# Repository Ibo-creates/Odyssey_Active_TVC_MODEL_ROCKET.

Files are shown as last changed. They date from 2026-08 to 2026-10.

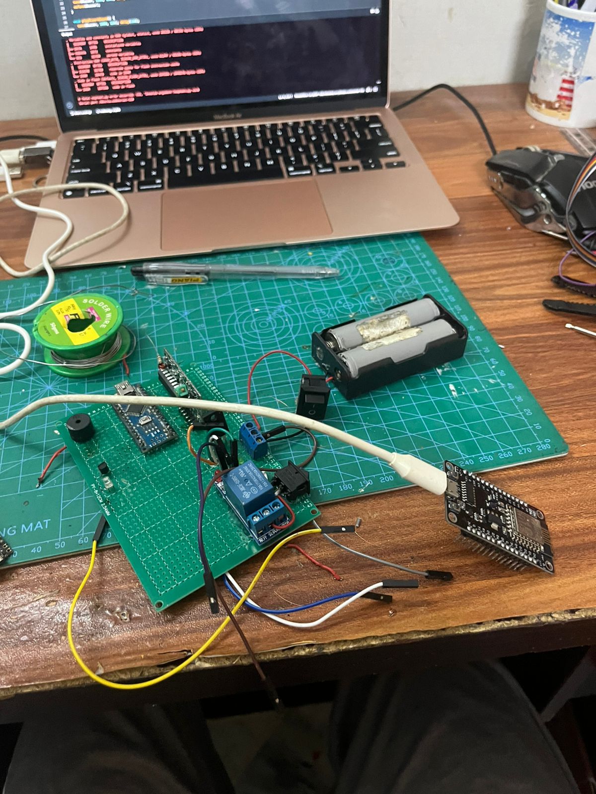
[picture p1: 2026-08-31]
media/LaunchPad ignition /images/Debugging setup.jpeg

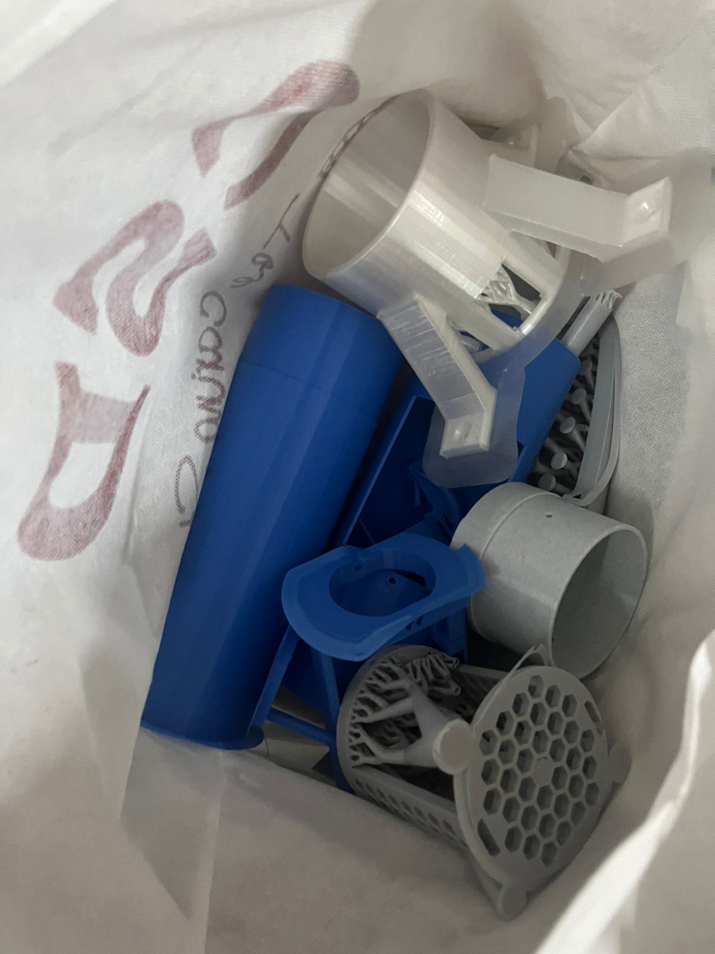
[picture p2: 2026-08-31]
media/rocket/images/Raw parts.jpeg

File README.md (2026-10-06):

# 🚀 Odyssey

rocekt

### A Thrust Vector Controlled Rocket

> **Odyssey** is an actively stabilized rocket featuring a custom 2-axis Thrust Vector Control (TVC) system with a parachute mechansim , a custom flight computer packed MPU6050 IMU, PID-based control, and onboard flight-data logging, which handles , G-forces, yaw, pitch and PID calulations.
> This also includes a custom launch radio remote Igniton system.

## Overview

### Demo: https://youtube.com/shorts/ixf_WoA4taA?si=kmYzy9-NjBv1ve3l

(A flight hasnt be logged yet due to restrictions of commerically available rocket motors in my country)

It has been a dream of mine to build a guided rocket, for which I explored an alternative method to conventional fins rocket stablization, and Thrust vector control instead. This works by moving the rocket's motor using a custom 2 axis servo gimble, yaw and pitch, relying on correction angles received from the flight computer running a custom PID algrothim. 

Odyssey also has a custom Launch-pad radio controlled Igniton system, which helps ignite the rocket's motor safely using custom e-matches. 

At apogee the rocket's mechnical nose opens with the help of a servo, revealing a parachute that brings the rocket back safely to the ground.

The flight log data is then recorded into a 8 gb SD card, which can be later read and visualised using excel 2d graphs feature. 

## Features

### Rocket

* Dry mass of approximately: 1kg
* height: 60 cm
* Outer diameter : 9.2 cm
* Rocket motor class to be used : Estes G class motor

* Vertical IMU Mounting: Custom math engine tailored for vertical IMU orientation.
* Flight State Machine: Automated transitions through PAD, IGNITION, COAST, APOGEE, and LANDED states.
* Barometric and IMU Telemetry: Live logging of altitude, acceleration, attitude angles, and PID servo outputs directly to an onboard microsd card.
* Fully custom 3d printed design.
* 2-axis TVC gimble.
* Automatic parachute mechanical syetem at apogee.
* Onboard data logging.

### Wireless Launch System

* Wireless launch command
* 3 step launch verfication.
* Remote ignition control
* Launch system status indicator

### Parameters logged

| Parameter | Description |
| --- | --- |
| Time_ms | Timestamp |
| State | Current flight state |
| Pitch | Estimated pitch angle |
| Yaw | Estimated yaw angle |
| Altitude | BMP280 altitude |
| GForce | Calculated total acceleration |
| OutputPitch | TVC pitch correction |
| OutputYaw | TVC yaw correction |

The controller continuously compares the desired Yaw and Pitch with the measured ones. The resulting error is processed by the PID controller, which generates a TVC command. The Output result then send a correction angle for the servos to move in a way that steers the rocket back to the vertical axis, the loop repeats until desired postion is reached.

## Flight state machine

PAD
 │
 │ Liftoff detected
 
IGNITION
 │
 │ Burnout detected
 
COAST
 │
 │ Apogee detected
 
APOGEE
 │
 │ Deployment
 
LANDED
## Control and Mathematics Overview

### PID Control math 

Odyssey uses a PD controller to convert attitude error into TVC servo corrections:

#### Controller Parameters

| Axis  |  Kp |  Ki | Kd |
| ----- | --: | --: | ---: |
| Pitch | 1.2 | 0 | 0.05 |
| Yaw | 2.0 | 0 | 0.10 |

## Hardware Electronics 

### Flight computer

|  # | Component | Quantity |
| -: | :--- | ---: |
|  1 | Arduino Uno | 1 |
|  2 | MPU6050 IMU | 1 |
|  3 | BMP280 Barometric Sensor | 1 |
|  4 | MicroSD Card Module | 1 |
|  5 | Servo Motors | 3 |
|  6 | Buzzer | 1 |
|  7 | NPN Transistor | 1 |
|  8 | 5mm Green LED | 1 |
|  9 | Toggle Switch | 1 |
| 10 | LM7805 5V Voltage Regulator | 2 |
| 11 | 18650 Li-ion Cells | 2 |
| 12 | 4 × 6 cm Perfboard | 1 |
| 13 | M4 × 6 mm Screws | 14 |

### LaunchPad igniton
|  # | Component | Quantity |
| -: | --- | ---: |
|  1 | Arduino MKR WiFi 1000 | 1 |
|  2 | 4-Channel NIC2262/2272 Wireless Remote + Receiver Module | 1 |
|  3 | 5V Relay | 1 |
|  4 | LM7805 5V Voltage Regulator | 1 |
|  5 | Buzzer | 1 |
|  6 | NPN Transistor | 1 |
|  7 | 5mm LED | 1 |
|  8 | Diode | 1 |
|  9 | ON/OFF Switch | 1 |
| 10 | 18650 Li-ion Cells | 3 |
| 11 | 8 × 12 cm Perfboard. | 1 |

## Pinout and Wiring

### Flight computer

| Arduino Uno Pin | Component | Function |
| --- | --- | --- |
| **A4 / SDA** | MPU6050 | I²C Data |
| **A5 / SCL** | MPU6050 | I²C Clock |
| **A4 / SDA** | BMP280 | I²C Data |
| **A5 / SCL** | BMP280 | I²C Clock |
| **D10** | SD Card | Chip Select |
| **D11** | SD Card | MOSI |
| **D12** | SD Card | MISO |
| **D13** | SD Card | SCK |
| **D5** | TVC Servo X | Pitch control |
| **D6** | TVC Servo Y | Yaw control |
| **D9** | Chute Servo | Parachute deployment |
| **D3** | Buzzer | Audio status |
| **D2** | Green LED | Status indicator |

### Ignition launch pad

| Arduino Pin | Connected To | Function |
| --- | --- | --- |
| **D3** | Radio Receiver CH1 | Sequence input 1 |
| **D4** | Radio Receiver CH2 | Sequence input 2 |
| **D5** | Radio Receiver CH3 | Sequence input 3 |
| **D6** | Relay control | Launch output |
| **D7** | Green LED | Status |
| **D1** | Buzzer | Audio feedback |

## Onshape Public link: 

https://cad.onshape.com/documents/43eb36db9af5306ca3d18e96/w/deaf376eb42987b9b3412347/e/4c195a71d6f593436827596b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

## Software Setup

Required Arduino Libraries
Install the following libraries using the Arduino Library Manager:

1.Adafruit BMP280 Library
2.Servo library 
3.Wire & SPI (Built-in)

### How to upload the code

1. Copy the code from firware repositry
2. select your com port where the arduino is attached
3. Select the right board e.g " Arduino uno"
4. Click upload

## Sd card data logging

### Heres how to read the data from sd card

1. Take out the sd card from the flight computer.
2. Insert it into a laptop or pc using an sd card reader usb.
3. Export the LOG.csv files into excel, google sheets or numbers ( for mac).
4. Make a Seperate column left to the Time_ms, and write to the 2nd row of the new column " = B2/1000 " , drag the yellow box to the end of the column.
5. Filter the time period you want to visualise.
6. Select the two columns you would like to plot on a 2d graph, e.g Altitude at Y axis and Time in seconds in X axis.
7. Click on the " insert " option, select the " Scatter graph with smooth lines " .

---

**Odyssey — Ground Tested · Flight Pending**

Built for **Hack Club Macondo 2026**.

## License

Software in this repository is released under the **MIT License**.

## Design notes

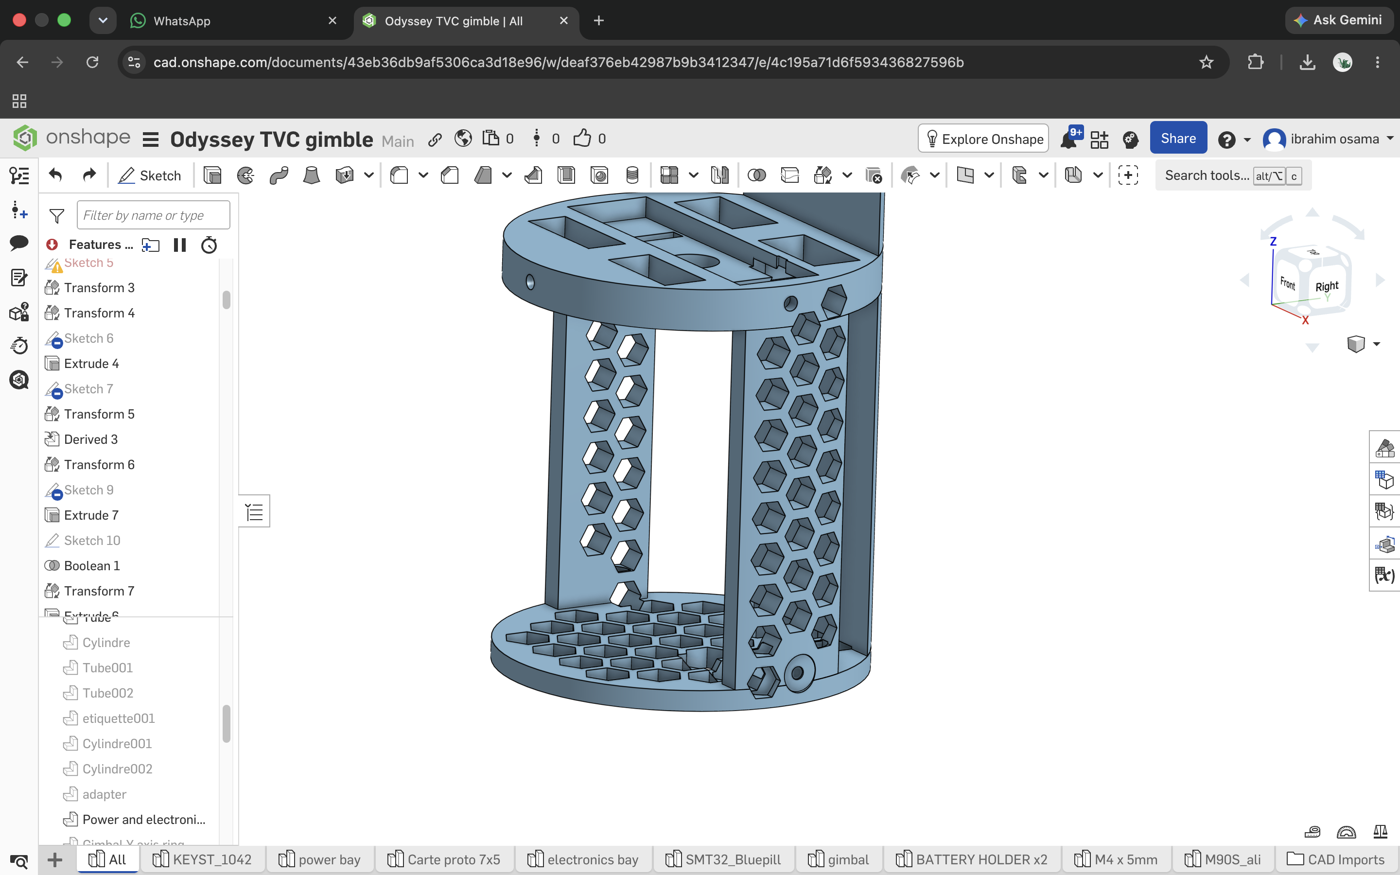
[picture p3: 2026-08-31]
media/rocket/images/Electronics bay.png

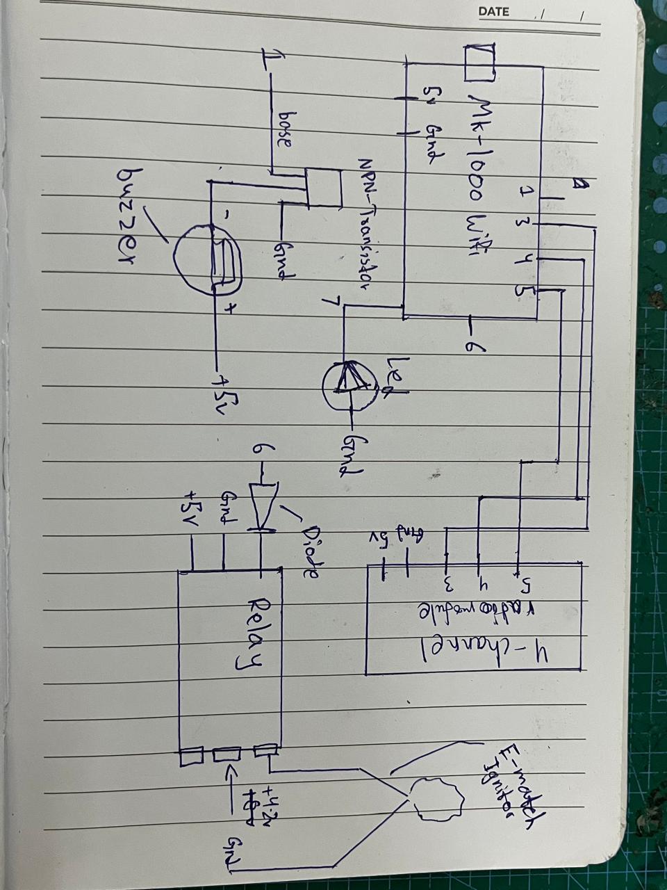
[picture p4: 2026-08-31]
Wiring diagram /Launch pad Ignition/Electronics.jpeg

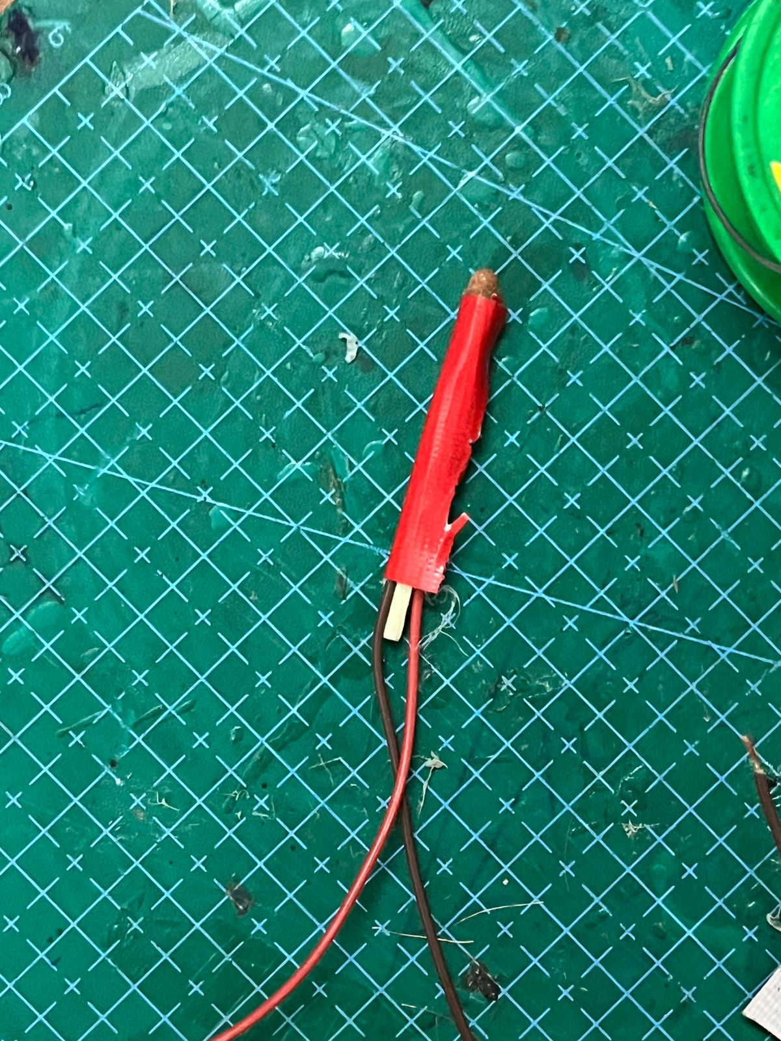
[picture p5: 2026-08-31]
media/LaunchPad ignition /images/E match.jpeg

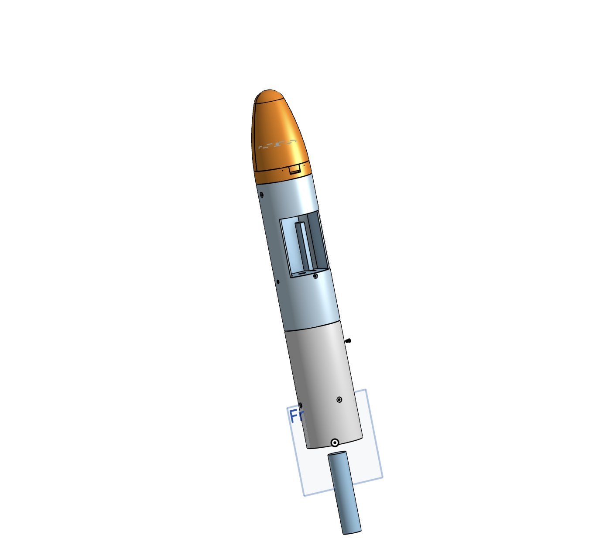
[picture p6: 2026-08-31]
media/rocket/images/Cad rocket.png

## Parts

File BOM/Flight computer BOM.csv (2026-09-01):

# | Component | Specification | Qty | Cost | Supplier | Link
1 | Arduino Uno | ATmega328P | 1 | $ 27.6 | Amazon | https://www.amazon.com/Arduino-A000066-ARDUINO-UNO-R3/dp/B008GRTSV6?utm_source=chatgpt.com
2 | MPU6050 | 6-Axis IMU | 1 | $ 8.99 | Amazon | https://www.amazon.com/dp/B09TVYVC6X
3 | BMP280 | Barometric Sensor | 1 | $5.49 | Amazon | https://www.amazon.com/dp/B01ICN5QPU
4 | MicroSD Module | SPI | 1 | $6.99 | Amazon | https://www.amazon.com/dp/B07BJ2P6X6
5 | MicroSD Card | 8 GB | 1 | $11.84 | Amazon | https://www.amazon.com/dp/9983039281
7 | Mg 90 Servo Motor | Parachute Deployment/ gamble | 3 | $8.68 x 3 = $26.04 | Amazon | https://www.amazon.com/dp/B0BHYHKF2P
8 | Active Buzzer | 5 V | 1 | $7.99 | Amazon | https://www.amazon.com/QMseller-Terminals-Raspberry-Electronic-Continous/dp/B07VRK7ZPF
9 | NPN Transistor | Switching / Driver | 1 | $8.99 | Amazon | https://www.amazon.ca/-/fr/2N3904-Power-transistors-jonction-bipolaire/dp/B0DMVQSLWF?th=1
10 | Green LED | 5 mm | 1 | $7.99 | Amazon | https://www.amazon.com/dp/B01AUI4VVA?th=1
11 | Toggle Switch | Power | 1 | $6.99 | Amazon | https://www.amazon.com/-/es/EGSCST/dp/B0FH26ZN3N?th=1
12 | LM7805 | 5 V Regulator | 2 | $4.99 | Amazon | https://www.amazon.com/Regulator-Integrated-Circuits-Positive-Regulators/dp/B0BRV3YRK3?th=1
13 | 18650 Cell | Li-ion | 2 | $5.38 | Aliexpress | https://www.aliexpress.com/item/1005007910903881.html?utm_source=chatgpt.com
14 | Perfboard | 5 x 7 cm | 1 | $6.99 | Amazon | https://www.amazon.com/dp/B012YZ2Q4G?ref=clp_cat_p_2
15 | M4 pan head screws | 6mm | 14 | $6.99 | Amazon | https://www.amazon.com/dp/B07YS7RXN9
Total Cost | - | - | - | $143.26 | - | -

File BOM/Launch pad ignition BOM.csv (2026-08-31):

# | Component | Specification | Qty | Cost | Supplier | Link
1 | Arduino MKR WiFi 1000 | Microcontroller | 1 | $59.80 | Aliexpress | https://www.aliexpress.com/item/1005012576306573.html
2 | Wireless Rf remote module | IC2272 4-Channel Wireless RF Transceiver Module | 1 | $12.99 | Amazon | https://www.amazon.ca/Channel-Wireless-Control-Transmitter-Receiver/dp/B00XDTG644
3 | Relay | 5 V | 1 | $1.86 | Aliexpress | https://www.aliexpress.com/item/1005012716803241.html
4 | LM7805 | 5 V Regulator | 1 | $4.99 | Amazon | https://www.amazon.com/Regulator-Integrated-Circuits-Positive-Regulators/dp/B0BRV3YRK3?th=1
5 | Buzzer | 5 V | 1 | $7.99 | Amazon | https://www.amazon.com/QMseller-Terminals-Raspberry-Electronic-Continous/dp/B07VRK7ZPF
6 | NPN Transistor | Switching / Driver | 1 | $8.99 | Amazon | https://www.amazon.ca/-/fr/2N3904-Power-transistors-jonction-bipolaire/dp/B0DMVQSLWF?th=1
7 | Green LED | 5 mm | 1 | $7.99 | Amazon | https://www.amazon.com/dp/B01AUI4VVA?th=1
8 | Diode | Relay protection | 1 | $6.99 | Amazon | https://www.amazon.com/dp/B083DXTTXS
9 | ON/OFF Switch | Main Power | 1 | $5.99 | Amazon | https://www.amazon.com/clp/B01N2U8PK0
10 | 18650 Cell | Li-ion | 3 | $8.07 | Amazon | https://www.aliexpress.com/item/1005007910903881.html?utm_source=chatgpt.com
11 | Perfboard | 8 × 12 cm | 1 | $5.54 | Aliexpress | https://www.aliexpress.com/item/1890414289.html
Total Cost | - | - | - | $131.2 | - | -

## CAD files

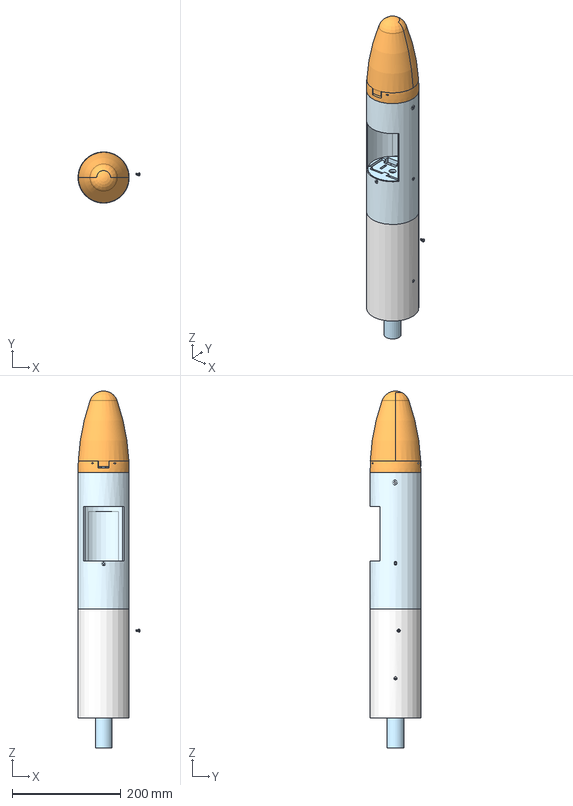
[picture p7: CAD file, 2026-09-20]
Assembly 1 (1).step
113.8 x 94.0 x 655.2 mm
Gimabl X axis ring
etiquette001 x 3
axe x 3
Cylindre002 x 3
Tube x 3
Power and electronics bay
Nose seat
etiquette x 3
Gimbal Y axis ring
Tube002 x 3
M4 x 5mm v2
Lower tube
Cylindre x 3
base001 x 3
Cylindre001 x 3
Upper tube
Tube001 x 3
Nose flap 1
Nose base
adapter
Nose flap 2
Motor tube
motortube

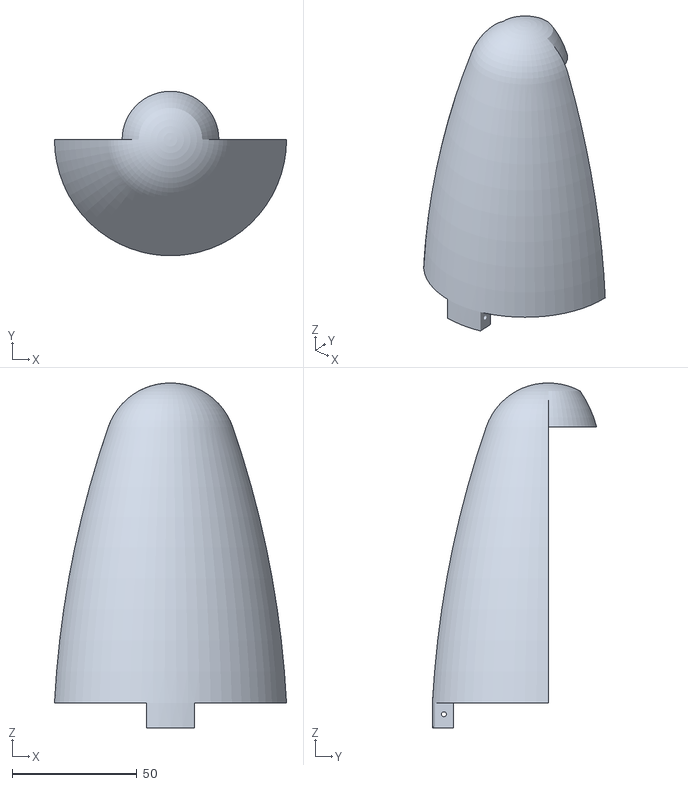
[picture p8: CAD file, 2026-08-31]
3d models /3d printing models/All - Nose flap 2.stl
92.9 x 65.8 x 138.1

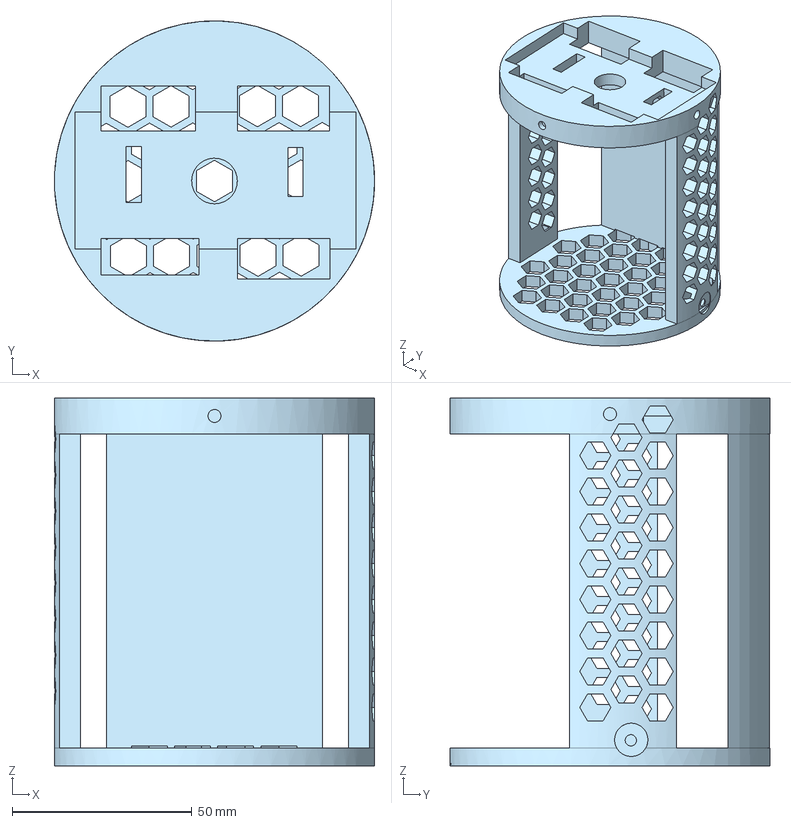
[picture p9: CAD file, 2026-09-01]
3d models /Step models/All - Power and electronics bay (1).step
89.0 x 89.0 x 102.3 mm

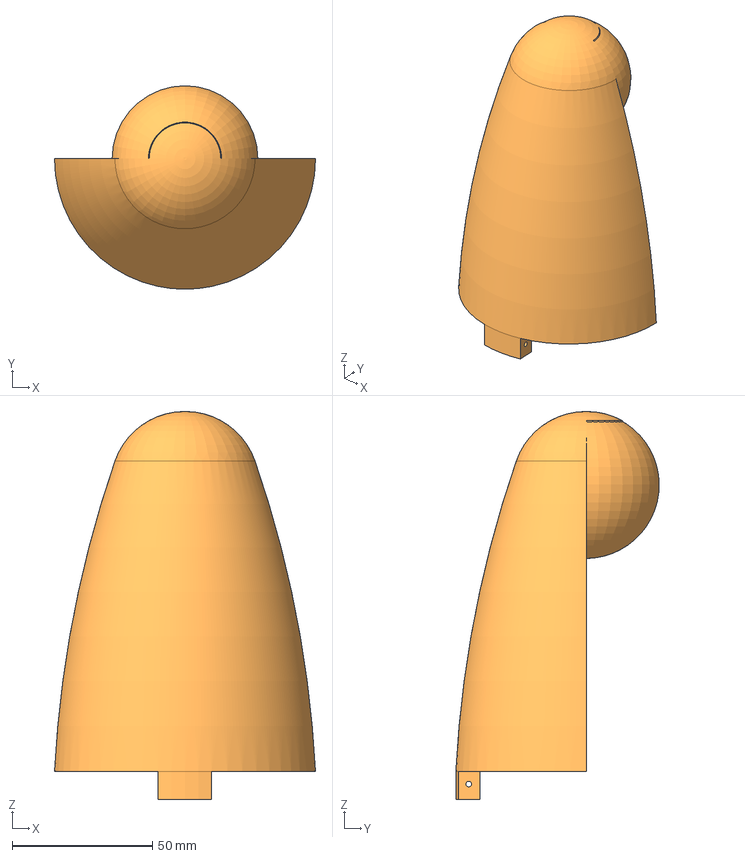
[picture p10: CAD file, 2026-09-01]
3d models /Step models/All - Nose flap 2 (1).step
92.9 x 72.4 x 138.1 mm

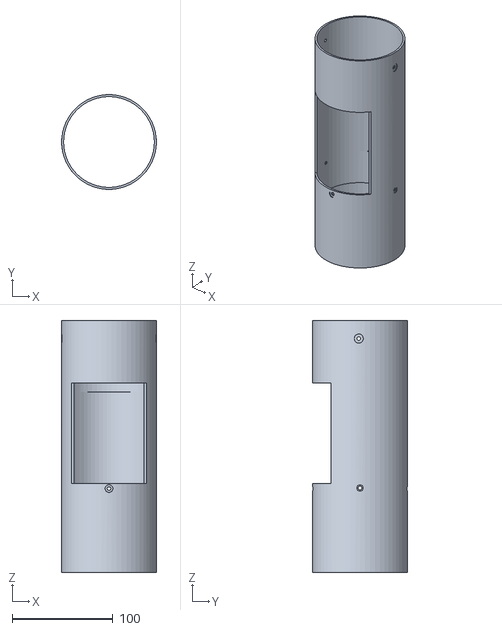
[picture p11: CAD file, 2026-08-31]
3d models /3d printing models/All - Upper tube.stl
94.0 x 94.0 x 250.0

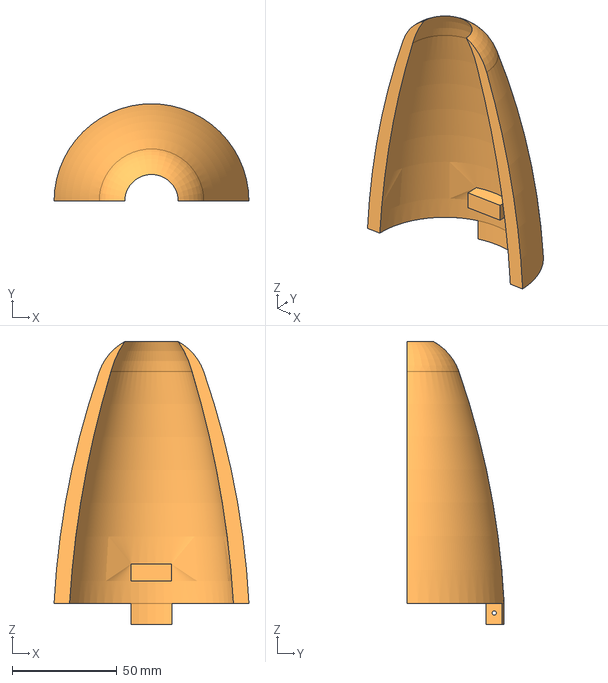
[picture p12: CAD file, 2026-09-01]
3d models /Step models/All - Nose flap 1 (1).step
92.9 x 46.5 x 134.9 mm

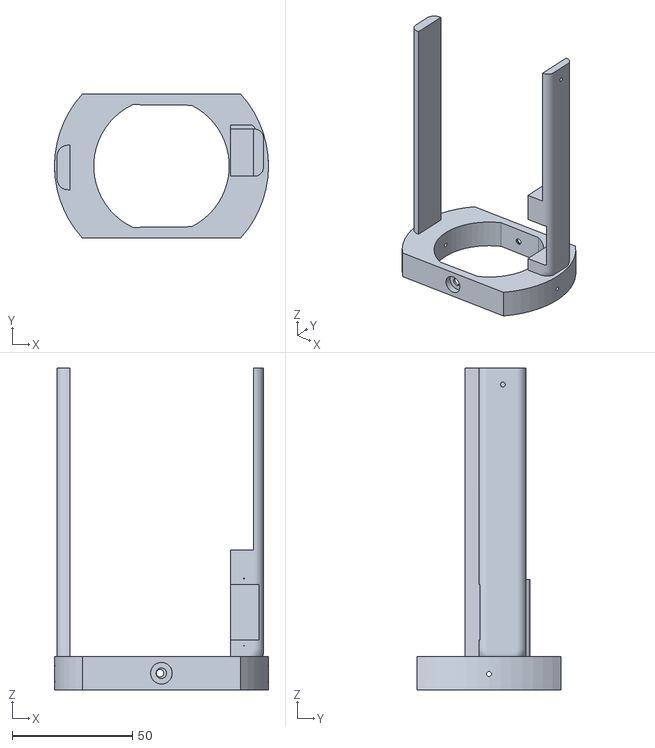
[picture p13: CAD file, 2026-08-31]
3d models /3d printing models/All - Gimabl X axis ring (3).stl
89.0 x 60.0 x 133.9

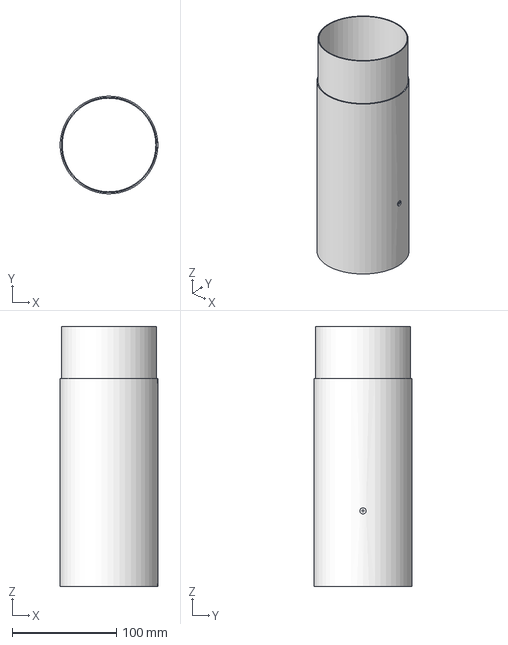
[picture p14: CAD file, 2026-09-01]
3d models /Step models/All - Lower tube (1).step
94.0 x 94.0 x 250.0 mm

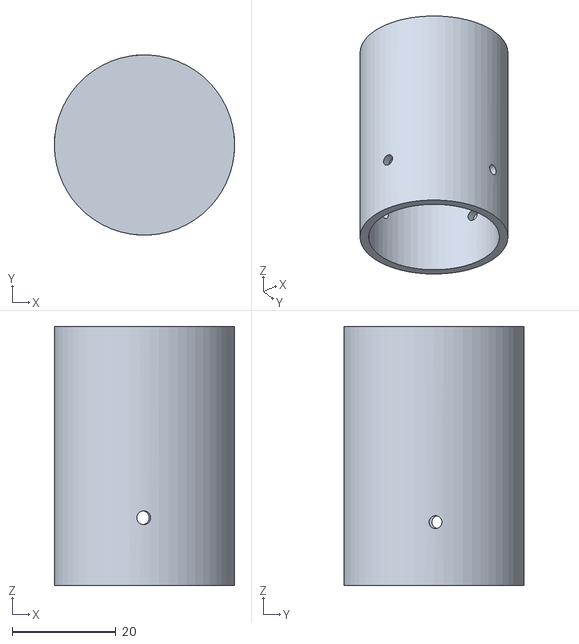
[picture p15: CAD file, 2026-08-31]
3d models /3d printing models/All - Motor tube.stl
34.8 x 34.8 x 50.0

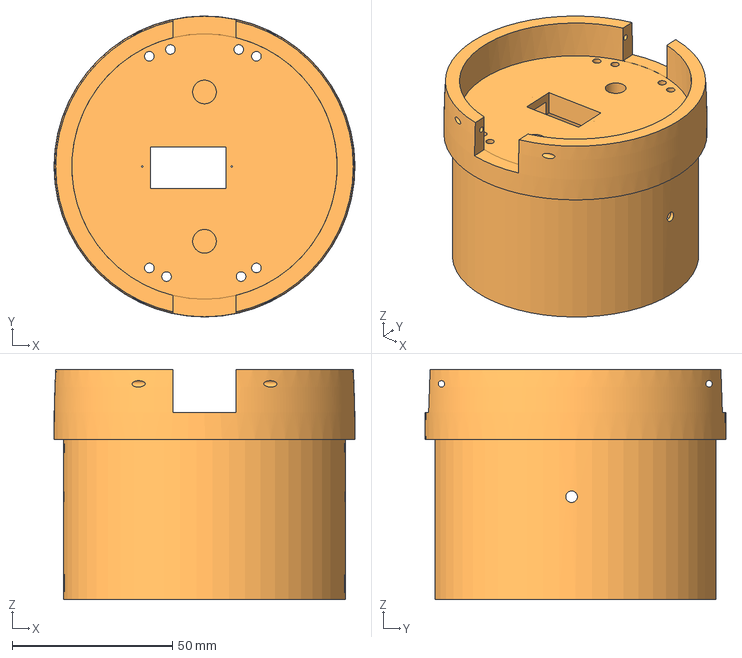
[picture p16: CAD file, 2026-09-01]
3d models /Step models/All - Nose base (1).step
94.0 x 94.0 x 71.9 mm

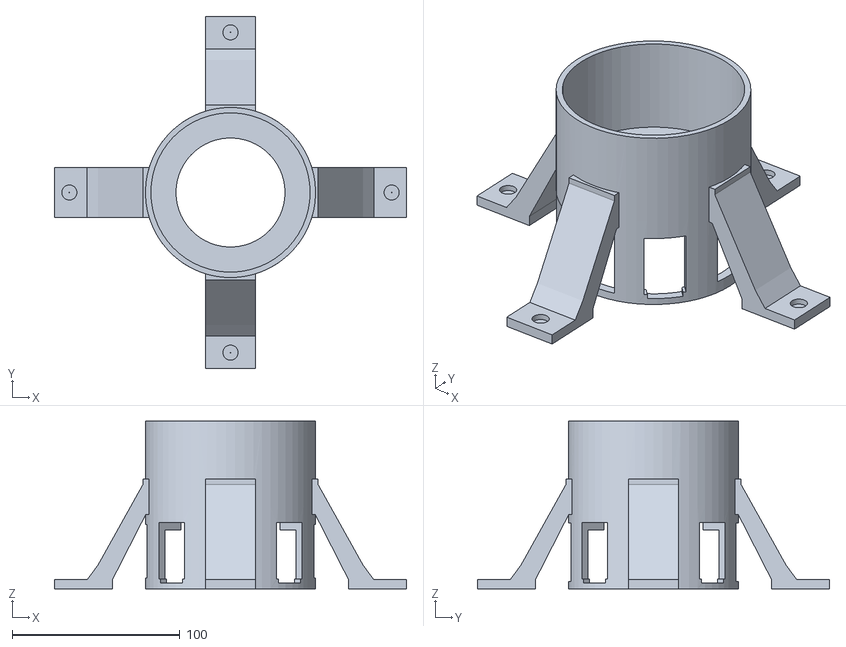
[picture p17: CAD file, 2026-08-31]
3d models /3d printing models/Launchpad.stl
210.0 x 210.0 x 100.0

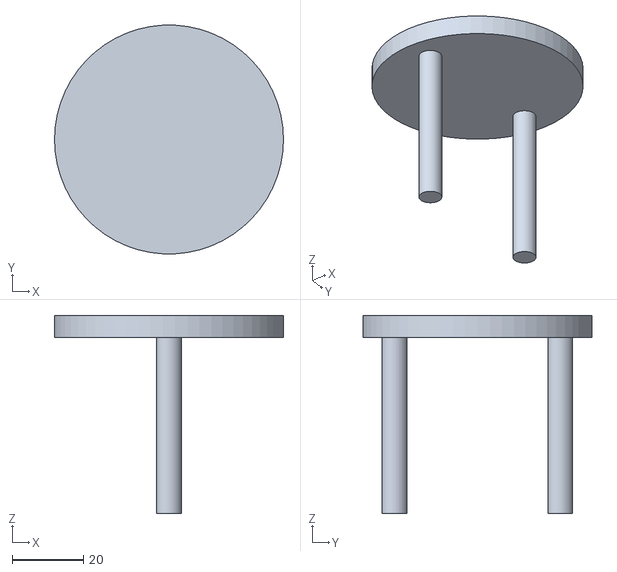
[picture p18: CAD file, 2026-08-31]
3d models /3d printing models/All - Nose seat (1).stl
64.4 x 64.3 x 55.8

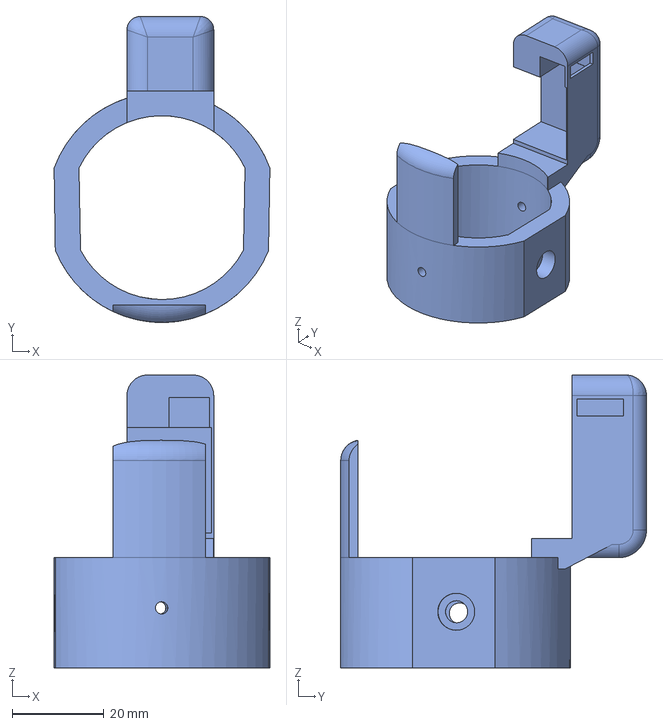
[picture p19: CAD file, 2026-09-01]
3d models /Step models/All - Gimbal Y axis ring (1).step
46.9 x 66.6 x 63.7 mm

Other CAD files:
3d models /3d printing models/All - Power and electronics bay (4).stl
3d models /Step models/All - Upper tube (1).step
3d models /3d printing models/All - Nose flap 1.stl
3d models /Step models/All - Motor tube (1).step
3d models /3d printing models/All - Nose base (5).stl
3d models /3d printing models/All - Gimbal Y axis ring (1).stl
3d models /3d printing models/All - Lower tube (1).stl
3d models /Step models/All - Gimabl X axis ring (1).step
3d models /Step models/All - Nose seat.step
3d models /Step models/Part Studio 1 - luanchpad.step

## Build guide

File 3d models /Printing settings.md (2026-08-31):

### 3D Printing Specifications

**Printer Nozzle:** 0.4 mm

Supports: On 
Filament: PETG

| Part | Material | Infill |
| --- | --- | -----: |
| Adapter | White | 15% |
| Gimbal X | Blue | 25% |
| Gimbal Y | White | 25% |
| Lower Tube | Blue | 100% |
| Motor Tube | Blue | 100% |
| Nose Base | White | 15% |
| Nose Flap 1 | White | 15% |
| Nose Flap 2 | White | 15% |
| Nose Seat | Blue | 25% |
| Power & Electronics Bay | White | 15% |
| Upper Tube | Blue | 100% |

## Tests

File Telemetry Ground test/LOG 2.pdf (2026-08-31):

## Altitude

## State

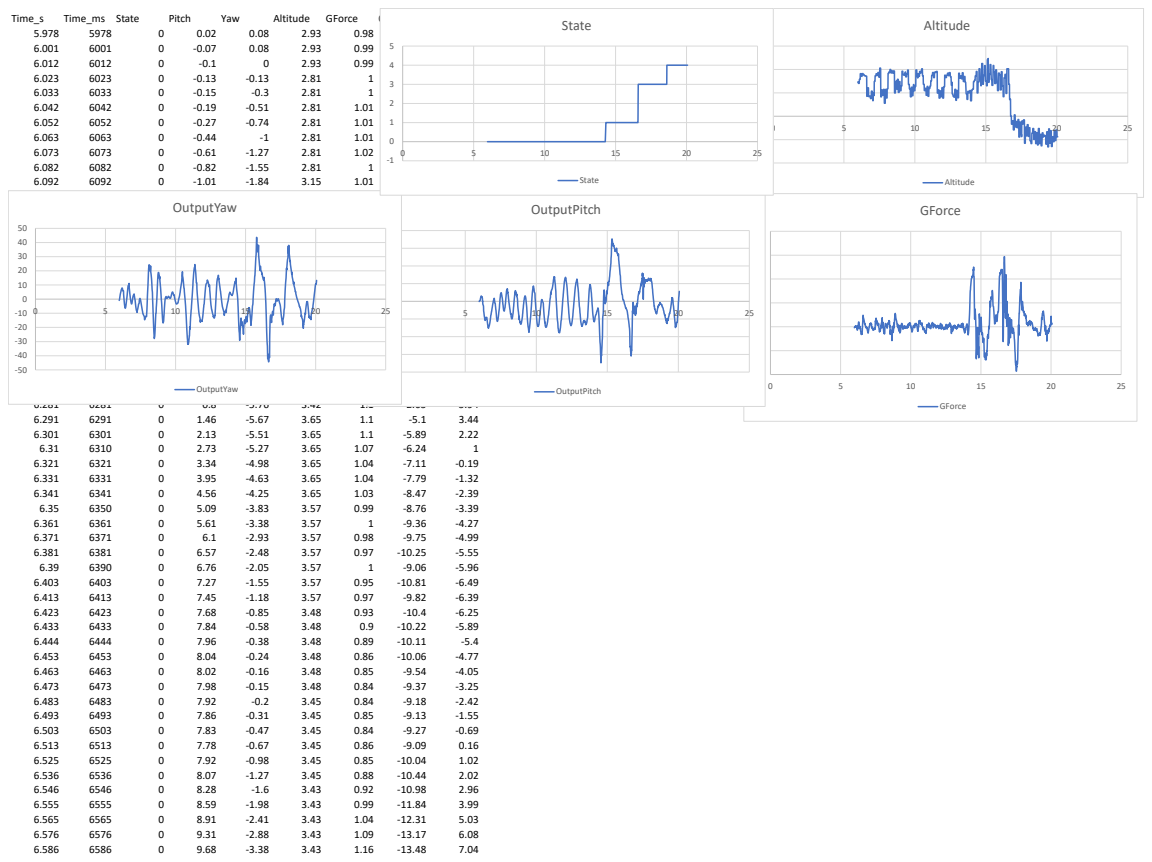
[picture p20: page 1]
Time_s; Time_ms State; Pitch; Yaw; Altitude; GForce; OutputPitchOutputYaw; OutputPitch; OutputYaw; State

6.147 6147 | 0 | -1.89 | -3.5 3.15 | 30 0.99
6.157 6157 | 0 | -1.95 | -3.84 3.64 | 20 0.97

2.7 7.08
2.66 7.41

6.197 6197 | 0 | -1.97 | -5.08 3.64 | 0.93 -20
6.207 6207 | 0 | -1.83 | -5.32 3.64 | 0.95 -30

1.99 7.74
1.54 7.47

6.595 | 6595
0 | 10.15 | -3.91 | 3.43 | 1.24 | -14.55 | 7.95
6.605 | 6605
0 | 10.59 | -4.45 | 3.43 | 1.24 | -14.88 | 8.69
6.616 | 6616
0 | 10.93 | -4.98 | 1.7 | 1.21 | -14.81 | 9.22
6.626 | 6626
0 | 11.24 | -5.5 | 1.7 | 1.18 | -15.03 | 9.52
6.635 | 6635
0 | 11.51 | -5.97 | 1.7 | 1.18 | -15.15 | 9.56
6.645 | 6645
0 | 11.69 | -6.38 | 1.7 | 1.17 | -14.94 | 9.31
6.683 | 6683
0 | 11.53 | -7.48 | 2.43 | 1.12 | -13.63 | 11.1
6.692 | 6692
0 | 11.51 | -7.67 | 2.43 | 1.1 | -13.68 | 8.29
6.703 | 6703
0 | 11.43 | -7.77 | 2.43 | 1.08 | -13.32 | 7.17
6.713 | 6713
0 | 11.3 | -7.79 | 2.43 | 1.06 | -12.9 | 6.08
6.723 | 6723
0 | 11.13 | -7.74 | 2.43 | 1.07 | -12.51 | 5.06
6.732 | 6732
0 | 10.93 | -7.63 | 2.43 | 1.05 | -12.12 | 4.1
6.743 | 6743
0 | 10.68 | -7.49 | 1.68 | 1.04 | -11.59 | 3.22
6.753 | 6753
0 | 10.38 | -7.31 | 1.68 | 1.04 | -10.9 | 2.38
6.763 | 6763
0 | 10.05 | -7.1 | 1.68 | 1.03 | -10.45 | 1.58
6.772 | 6772
0 | 9.66 | -6.86 | 1.68 | 1.02 | -9.61 | 0.8
6.782 | 6782
0 | 9.26 | -6.6 | 1.68 | 1.02 | -9.16 | 0.06
6.793 | 6793
0 | 8.79 | -6.32 | 1.68 | 0.99 | -8.17 | -0.65
6.805 | 6805
0 | 8.24 | -5.96 | 1.68 | 1 | -7.7 | -1.26
6.815 | 6815
0 | 7.87 | -5.67 | 1.71 | 0.98 | -7.62 | -1.92
6.825 | 6825
0 | 7.45 | -5.37 | 1.71 | 0.99 | -6.81 | -2.46
6.836 | 6836
0 | 7.05 | -5.06 | 1.71 | 1 | -6.48 | -2.91
6.845 | 6845
0 | 6.63 | -4.77 | 1.71 | 0.97 | -5.82 | -3.24
6.855 | 6855
0 | 6.27 | -4.5 | 1.71 | 0.97 | -5.73 | -3.41
6.865 | 6865
0 | 5.88 | -4.26 | 1.71 | 0.99 | -5.13 | -3.4
6.876 | 6876
0 | 5.48 | -4.06 | 1.51 | 0.98 | -4.54 | -3.21
6.885 | 6885
0 | 5.08 | -3.91 | 1.51 | 0.98 | -4.1 | -2.83
6.895 | 6895
0 | 4.67 | -3.82 | 1.51 | 0.95 | -3.59 | -2.3
6.905 | 6905
0 | 4.29 | -3.79 | 1.51 | 0.93 | -3.2 | -1.67
6.916 | 6916
0 | 3.85 | -3.82 | 1.51 | 0.93 | -2.46 | -1
6.925 | 6925
0 | 3.44 | -3.9 | 1.51 | 0.91 | -2.05 | -0.29
6.94 | 6940
0 | 2.86 | -4.09 | 2.15 | 0.88 | -1.42 | 0.41
6.949 | 6949
0 | 2.47 | -4.25 | 2.15 | 0.89 | -1.03 | 1.15
6.96 | 6960
0 | 2.11 | -4.44 | 2.15 | 0.87 | -0.74 | 1.71
6.97 | 6970
0 | 1.71 | -4.65 | 2.15 | 0.87 | -0.03 | 2.15
6.98 | 6980
0 | 1.34 | -4.86 | 2.15 | 0.9 | 0.24 | 2.47
6.989 | 6989
0 | 1 | -5.06 | 2.15 | 0.91 | 0.48 | 2.66
7.038 | 7038
0 | -0.3 | -5.81 | 1.33 | 1 | 1.71 | 3.66
7.05 | 7050
0 | -0.38 | -5.93 | 1.33 | 1 | 0.82 | 2.87
7.06 | 7060
0 | -0.37 | -5.99 | 1.33 | 1.02 | 0.38 | 2.29
7.069 | 7069
0 | -0.29 | -5.99 | 1.96 | 1.03 | -0.07 | 1.7
7.079 | 7079
0 | -0.12 | -5.95 | 1.96 | 1.06 | -0.69 | 1.04
7.09 | 7090
0 | 0.1 | -5.85 | 1.96 | 1.05 | -1.21 | 0.31
7.112 | 7112
0 | 0.45 | -5.48 | 1.96 | 1.06 | -1.3 | -0.76
7.122 | 7122
0 | 0.78 | -5.26 | 1.96 | 1.07 | -2.59 | -1.82
7.133 | 7133
0 | 1.11 | -4.99 | 1.77 | 1.07 | -3 | -2.75
7.142 | 7142
0 | 1.54 | -4.67 | 2.98 | 1.08 | -3.97 | -3.66
7.152 | 7152
0 | 2 | -4.31 | 2.98 | 1.08 | -4.74 | -4.53
7.162 | 7162
0 | 2.44 | -3.92 | 2.98 | 1.08 | -5.11 | -5.39
7.173 | 7173
0 | 2.97 | -3.5 | 2.98 | 1.04 | -6.23 | -6.15
7.183 | 7183
0 | 3.53 | -3.07 | 2.98 | 1.04 | -6.99 | -6.81
7.192 | 7192
0 | 4.11 | -2.63 | 2.98 | 1.04 | -7.88 | -7.41
7.202 | 7202
0 | 4.8 | -2.18 | 3.46 | 1.06 | -9.19 | -7.87
7.213 | 7213
0 | 5.41 | -1.75 | 3.46 | 0.98 | -9.53 | -8.15
7.223 | 7223
0 | 6 | -1.35 | 3.46 | 1 | -10.17 | -8.31
7.232 | 7232
0 | 6.57 | -0.97 | 3.46 | 0.98 | -10.71 | -8.34
7.25 | 7250
0 | 7.44 | -0.36 | 3.46 | 0.98 | -11.36 | -9.39

7.261 | 7261
0 | 7.82 | -0.07 | 3.46 | 0.97 | -11.31 | -8.33
7.27 | 7270
0 | 8.12 | 0.19 | 3.63 | 0.96 | -11.24 | -8.03
7.28 | 7280
0 | 8.33 | 0.42 | 3.63 | 0.95 | -11.03 | -7.7
7.29 | 7290
0 | 8.44 | 0.6 | 3.63 | 0.95 | -10.67 | -7.32
7.301 | 7301
0 | 8.48 | 0.75 | 3.63 | 0.93 | -10.38 | -6.89
7.31 | 7310
0 | 8.41 | 0.86 | 3.63 | 0.93 | -9.76 | -6.42
7.32 | 7320
0 | 8.26 | 0.94 | 3.63 | 0.96 | -9.14 | -5.91
7.33 | 7330
0 | 8.05 | 0.98 | 3.48 | 0.97 | -8.61 | -5.35
7.341 | 7341
0 | 7.75 | 0.99 | 3.48 | 0.94 | -7.8 | -4.74
7.351 | 7351
0 | 7.4 | 0.96 | 3.48 | 0.94 | -7.15 | -4.09
7.36 | 7360
0 | 6.98 | 0.89 | 3.48 | 0.96 | -6.28 | -3.43
7.398 | 7398
0 | 5.27 | 0.47 | 3.74 | 0.94 | -4.04 | -3.05
7.408 | 7408
0 | 4.71 | 0.32 | 3.74 | 0.95 | -2.86 | -1.43
7.417 | 7417
0 | 4.05 | 0.14 | 3.74 | 0.97 | -1.55 | -0.78
7.428 | 7428
0 | 3.41 | -0.05 | 3.74 | 0.95 | -0.91 | -0.25
7.438 | 7438
0 | 2.67 | -0.24 | 3.74 | 0.97 | 0.52 | 0.14
7.448 | 7448
0 | 1.91 | -0.42 | 3.74 | 0.96 | 1.52 | 0.4
7.458 | 7458
0 | 1.2 | -0.58 | 3.74 | 0.95 | 2.06 | 0.48
7.468 | 7468
0 | 0.52 | -0.71 | 3.34 | 1.05 | 2.81 | 0.38
7.478 | 7478
0 | -0.19 | -0.8 | 3.34 | 1.12 | 3.75 | 0.14
7.488 | 7488
0 | -0.82 | -0.84 | 3.34 | 1.11 | 4.14 | -0.19
7.498 | 7498
0 | -1.36 | -0.84 | 3.34 | 1.13 | 4.34 | -0.57
7.507 | 7507
0 | -1.83 | -0.8 | 3.34 | 1.14 | 4.57 | -1.04
7.518 | 7518
0 | -2.24 | -0.71 | 3.34 | 1.16 | 4.71 | -1.58
7.53 | 7530
0 | -2.59 | -0.55 | 4.12 | 1.18 | 4.55 | -2.28
7.54 | 7540
0 | -2.84 | -0.38 | 4.12 | 1.16 | 4.67 | -2.85
7.55 | 7550
0 | -2.98 | -0.17 | 4.12 | 1.13 | 4.23 | -3.47
7.56 | 7560
0 | -3 | 0.08 | 4.12 | 1.14 | 3.74 | -4.07
7.57 | 7570
0 | -2.98 | 0.35 | 4.12 | 1.1 | 3.46 | -4.67
7.58 | 7580
0 | -2.86 | 0.65 | 4.12 | 1.12 | 2.87 | -5.26
7.59 | 7590
0 | -2.69 | 0.98 | 4.03 | 1.07 | 2.34 | -5.83
7.6 | 7600
0 | -2.5 | 1.32 | 1.66 | 1.08 | 2.07 | -6.41
7.61 | 7610
0 | -2.25 | 1.69 | 1.66 | 1.04 | 1.47 | -6.99
7.62 | 7620
0 | -1.93 | 2.08 | 1.66 | 1.03 | 0.72 | -7.58
7.63 | 7630
0 | -1.53 | 2.49 | 1.66 | 1.03 | -0.19 | -8.13
7.641 | 7641
0 | -1.07 | 2.91 | 1.66 | 1.06 | -1 | -8.66
7.65 | 7650
0 | -0.58 | 3.34 | 1.66 | 1.07 | -1.76 | -9.14
7.662 | 7662
0 | -0.02 | 3.88 | 2.24 | 1.06 | -2.22 | -10.1
7.672 | 7672
0 | 0.5 | 4.32 | 2.24 | 1.04 | -3.19 | -10.12
7.683 | 7683
0 | 1.03 | 4.76 | 2.24 | 1.07 | -3.94 | -10.46
7.693 | 7693
0 | 1.54 | 5.2 | 2.24 | 1.03 | -4.39 | -10.75
7.702 | 7702
0 | 2.06 | 5.64 | 2.24 | 1.07 | -5.06 | -10.98
7.712 | 7712
0 | 2.44 | 6.06 | 2.24 | 1.02 | -4.85 | -11.2
7.723 | 7723
0 | 2.84 | 6.49 | 1.81 | 0.99 | -5.37 | -11.41
7.733 | 7733
0 | 3.16 | 6.91 | 1.81 | 0.98 | -5.39 | -11.62
7.743 | 7743
0 | 3.44 | 7.33 | 1.81 | 0.96 | -5.53 | -11.82
7.752 | 7752
0 | 3.64 | 7.75 | 1.81 | 0.93 | -5.36 | -12.01
7.762 | 7762
0 | 3.72 | 8.17 | 1.81 | 0.92 | -4.9 | -12.22
7.773 | 7773
0 | 3.68 | 8.59 | 1.81 | 0.89 | -4.2 | -12.41
7.792 | 7792
0 | 3.5 | 9.39 | 2.3 | 0.92 | -3.73 | -14.61
7.801 | 7801
0 | 3.35 | 9.8 | 2.3 | 0.92 | -3.29 | -13.15
7.812 | 7812
0 | 3.06 | 10.21 | 2.3 | 0.91 | -2.19 | -13.17
7.822 | 7822
0 | 2.73 | 10.6 | 2.3 | 0.92 | -1.62 | -13.14
7.832 | 7832
0 | 2.35 | 10.97 | 2.3 | 0.92 | -0.93 | -13.01
7.841 | 7841
0 | 1.9 | 11.32 | 2.3 | 0.95 | -0.04 | -12.88
7.852 | 7852
0 | 1.34 | 11.66 | 1.11 | 0.96 | 1.2 | -12.74
7.862 | 7862
0 | 0.73 | 11.99 | 1.11 | 0.97 | 2.16 | -12.6

7.872 | 7872
0 | 0.13 | 12.31 | 1.11 | 0.97 | 2.87 | -12.48
7.881 | 7881
0 | -0.52 | 12.61 | 1.11 | 1.03 | 3.83 | -12.37
7.891 | 7891
0 | -1.14 | 12.92 | 1.11 | 1.01 | 4.47 | -12.25
7.902 | 7902
0 | -1.85 | 13.21 | 1.11 | 1.06 | 5.77 | -12.11
7.912 | 7912
0 | -2.47 | 13.48 | 1.11 | 1.08 | 6.06 | -11.83
7.926 | 7926
0 | -3.07 | 13.8 | 2.29 | 1.09 | 5.79 | -12.35
7.936 | 7936
0 | -3.46 | 13.96 | 2.29 | 1.12 | 6.14 | -10.41
7.946 | 7946
0 | -3.91 | 14.01 | 2.29 | 1.15 | 6.93 | -8.99
7.956 | 7956
0 | -4.13 | 13.93 | 2.29 | 0.98 | 6.05 | -7.14
7.966 | 7966
0 | -4.45 | 13.69 | 2.29 | 1.19 | 6.95 | -4.86
7.976 | 7976
0 | -4.36 | 13.29 | 2.29 | 1.06 | 4.78 | -2.24
7.986 | 7986
0 | -4.38 | 12.71 | 1.56 | 1.1 | 5.34 | 0.54
7.996 | 7996
0 | -4.32 | 11.98 | 1.56 | 1.04 | 4.86 | 3.46
8.028 | 8028
0 | -3.58 | 9.1 | 1.56 | 1.09 | 3.14 | 9.43
8.041 | 8041
0 | -3.08 | 7.73 | 1.56 | 0.98 | 1.81 | 12.8
8.051 | 8051
0 | -2.68 | 6.58 | 2.35 | 0.99 | 1.21 | 15.18
8.061 | 8061
0 | -2.26 | 5.34 | 2.35 | 0.94 | 0.61 | 17.76
8.074 | 8074
0 | -1.6 | 3.74 | 2.35 | 0.89 | -0.77 | 20.85
8.083 | 8083
0 | -1.15 | 2.4 | 2.35 | 0.91 | -0.9 | 22.17
8.093 | 8093
0 | -0.66 | 1.08 | 2.35 | 0.91 | -1.67 | 23.36
8.103 | 8103
0 | -0.19 | -0.18 | 2.35 | 0.86 | -2.09 | 24.05
8.114 | 8114
0 | 0.3 | -1.36 | 3.67 | 0.97 | -2.81 | 24.29
8.123 | 8123
0 | 0.8 | -2.43 | 3.67 | 0.85 | -3.48 | 24.16
8.133 | 8133
0 | 1.29 | -3.41 | 3.67 | 0.86 | -3.98 | 23.79
8.143 | 8143
0 | 1.79 | -4.27 | 3.67 | 0.92 | -4.62 | 23.24
8.154 | 8154
0 | 2.24 | -5.03 | 3.67 | 0.99 | -4.95 | 22.55
8.163 | 8163
0 | 2.72 | -5.7 | 3.67 | 1.01 | -5.69 | 21.82
8.173 | 8173
0 | 3.21 | -6.29 | 3.67 | 1.03 | -6.27 | 21.09
8.183 | 8183
0 | 3.68 | -6.82 | 3.8 | 1.03 | -6.79 | 20.4
8.194 | 8194
0 | 4.15 | -7.28 | 3.8 | 1.07 | -7.33 | 19.74
8.219 | 8219
0 | 4.77 | -8.35 | 3.8 | 1.05 | -6.95 | 23.42
8.228 | 8228
0 | 5.24 | -8.73 | 3.8 | 1.05 | -8.6 | 19.32
8.239 | 8239
0 | 5.66 | -9.07 | 3.8 | 1.03 | -8.9 | 18.6
8.249 | 8249
0 | 6.09 | -9.36 | 4 | 1.03 | -9.48 | 17.83
8.259 | 8259
0 | 6.47 | -9.61 | 4 | 1.05 | -9.64 | 16.99
8.268 | 8268
0 | 6.79 | -9.81 | 4 | 1.03 | -9.77 | 16.04
8.279 | 8279
0 | 7.09 | -9.95 | 4 | 0.99 | -10 | 14.96
8.289 | 8289
0 | 7.31 | -10.02 | 4 | 1 | -9.9 | 13.68
8.299 | 8299
0 | 7.45 | -10.01 | 4 | 1 | -9.62 | 12.18
8.308 | 8308
0 | 7.55 | -9.9 | 3.85 | 0.98 | -9.57 | 10.45
8.318 | 8318
0 | 7.55 | -9.69 | 3.7 | 0.97 | -9.05 | 8.51
8.329 | 8329
0 | 7.51 | -9.36 | 3.7 | 1 | -8.79 | 6.41
8.348 | 8348
0 | 7.08 | -8.47 | 3.7 | 1.04 | -7.4 | 4.71
8.358 | 8358
0 | 6.87 | -7.89 | 3.7 | 1.07 | -7.18 | 0.86
8.368 | 8368
0 | 6.58 | -7.18 | 3.7 | 1.06 | -6.44 | -1.67
8.378 | 8378
0 | 6.2 | -6.35 | 3.88 | 1.07 | -5.57 | -4.27
8.388 | 8388
0 | 5.72 | -5.42 | 3.88 | 1.08 | -4.45 | -6.94
8.398 | 8398
0 | 5.16 | -4.36 | 3.88 | 1.08 | -3.4 | -9.68
8.409 | 8409
0 | 4.6 | -3.2 | 3.88 | 1.07 | -2.73 | -12.4
8.418 | 8418
0 | 3.96 | -1.94 | 3.88 | 1.07 | -1.5 | -15.1
8.428 | 8428
0 | 3.3 | -0.6 | 3.88 | 1.09 | -0.68 | -17.73
8.438 | 8438
0 | 2.62 | 0.81 | 3.88 | 1.09 | 0.23 | -20.18
8.449 | 8449
0 | 1.93 | 2.27 | 3.69 | 1.13 | 1.14 | -22.35
8.458 | 8458
0 | 1.25 | 3.74 | 3.69 | 1.11 | 1.94 | -24.18
8.468 | 8468
0 | 0.59 | 5.2 | 3.69 | 1.09 | 2.54 | -25.58
8.48 | 8480
0 | -0.26 | 6.95 | 3.69 | 1.12 | 3.71 | -27.85
8.491 | 8491
0 | -0.89 | 8.26 | 3.69 | 1.02 | 4.2 | -27.21

8.501 | 8501
0 | -1.42 | 9.45 | 3.69 | 1 | 4.34 | -26.94
8.511 | 8511
0 | -1.95 | 10.49 | 3.87 | 1.03 | 5.04 | -26.23
8.52 | 8520
0 | -2.34 | 11.37 | 3.87 | 0.99 | 4.73 | -24.97
8.53 | 8530
0 | -2.86 | 12.06 | 3.87 | 0.84 | 6.05 | -23.3
8.541 | 8541
0 | -3.02 | 12.55 | 3.87 | 0.87 | 4.44 | -21.15
8.551 | 8551
0 | -3.26 | 12.85 | 3.87 | 0.91 | 5.08 | -18.79
8.561 | 8561
0 | -3.35 | 12.96 | 3.87 | 0.89 | 4.49 | -16.38
8.57 | 8570
0 | -3.52 | 12.93 | 1.99 | 0.93 | 5.07 | -14.08
8.581 | 8581
0 | -3.65 | 12.77 | 1.99 | 0.93 | 5.03 | -11.85
8.591 | 8591
0 | -3.71 | 12.51 | 1.99 | 0.91 | 4.77 | -9.85
8.61 | 8610
0 | -3.37 | 11.89 | 1.99 | 0.9 | 3.2 | -9.77
8.621 | 8621
0 | -3.37 | 11.53 | 1.99 | 0.87 | 4.03 | -6.37
8.631 | 8631
0 | -3.27 | 11.15 | 1.99 | 0.87 | 3.4 | -5
8.641 | 8641
0 | -3.1 | 10.73 | 2.67 | 0.87 | 2.89 | -3.61
8.65 | 8650
0 | -2.85 | 10.26 | 2.67 | 0.89 | 2.17 | -2.11
8.66 | 8660
0 | -2.62 | 9.72 | 2.67 | 0.71 | 1.97 | -0.27
8.671 | 8671
0 | -2.32 | 9.08 | 2.67 | 0.88 | 1.28 | 1.83
8.681 | 8681
0 | -1.9 | 8.35 | 2.67 | 0.9 | 0.19 | 4.04
8.691 | 8691
0 | -1.24 | 7.52 | 2.67 | 0.97 | -1.84 | 6.37
8.7 | 8700
0 | -0.52 | 6.6 | 3.03 | 1.01 | -2.95 | 8.72
8.711 | 8711
0 | 0.21 | 5.59 | 2.33 | 0.95 | -3.91 | 10.95
8.721 | 8721
0 | 0.92 | 4.52 | 2.33 | 0.92 | -4.66 | 13.09
8.731 | 8731
0 | 1.62 | 3.4 | 2.33 | 0.95 | -5.43 | 14.93
8.743 | 8743
0 | 2.39 | 2.02 | 2.33 | 0.91 | -5.98 | 17.13
8.753 | 8753
0 | 3.01 | 0.93 | 2.33 | 0.88 | -6.76 | 17.78
8.763 | 8763
0 | 3.65 | -0.13 | 2.33 | 0.92 | -7.54 | 18.53
8.773 | 8773
0 | 4.2 | -1.13 | 3.16 | 0.93 | -7.84 | 18.85
8.783 | 8783
0 | 5.02 | -2.03 | 3.16 | 1 | -10.07 | 18.83
8.793 | 8793
0 | 5.42 | -2.86 | 3.16 | 1.08 | -8.53 | 18.73
8.803 | 8803
0 | 6.01 | -3.6 | 3.16 | 1 | -10.15 | 18.35
8.813 | 8813
0 | 6.51 | -4.26 | 3.16 | 0.98 | -10.29 | 17.85
8.823 | 8823
0 | 6.97 | -4.82 | 3.16 | 1.02 | -10.66 | 17.16
8.834 | 8834
0 | 7.42 | -5.29 | 2.04 | 1.07 | -11.14 | 16.34
8.843 | 8843
0 | 7.8 | -5.68 | 2.04 | 1.14 | -11.31 | 15.47
8.853 | 8853
0 | 8.23 | -6 | 2.04 | 1.17 | -12.01 | 14.58
8.872 | 8872
0 | 8.66 | -6.47 | 2.04 | 1.23 | -11.49 | 15.97
8.883 | 8883
0 | 8.98 | -6.64 | 2.04 | 1.23 | -12.33 | 12.95
8.893 | 8893
0 | 9.3 | -6.76 | 2.04 | 1.28 | -12.79 | 11.95
8.903 | 8903
0 | 9.57 | -6.82 | 2.97 | 1.26 | -12.83 | 10.92
8.912 | 8912
0 | 9.78 | -6.82 | 2.97 | 1.26 | -12.8 | 9.83
8.923 | 8923
0 | 9.98 | -6.76 | 2.97 | 1.23 | -12.97 | 8.69
8.933 | 8933
0 | 10.09 | -6.64 | 2.97 | 1.19 | -12.65 | 7.46
8.943 | 8943
0 | 10.15 | -6.46 | 2.97 | 1.18 | -12.5 | 6.1
8.952 | 8952
0 | 10.13 | -6.2 | 2.97 | 1.16 | -12.03 | 4.63
8.963 | 8963
0 | 10.07 | -5.87 | 2.18 | 1.14 | -11.81 | 3.06
8.973 | 8973
0 | 9.92 | -5.46 | 2.18 | 1.14 | -11.11 | 1.39
8.983 | 8983
0 | 9.75 | -4.98 | 2.18 | 1.13 | -10.86 | -0.31
9.004 | 9004
0 | 9.19 | -3.81 | 2.18 | 1.1 | -9.66 | -2.56
9.024 | 9024
0 | 8.53 | -2.43 | 2.18 | 1.05 | -8.66 | -5.92
9.035 | 9035
0 | 8.02 | -1.58 | 2.59 | 1.05 | -7.37 | -8.11
9.047 | 9047
0 | 7.53 | -0.72 | 2.59 | 1.03 | -6.71 | -10.02
9.056 | 9056
0 | 6.94 | 0.16 | 2.59 | 1 | -5.4 | -11.75
9.066 | 9066
0 | 6.36 | 1.09 | 2.59 | 1.02 | -4.69 | -13.35
9.076 | 9076
0 | 5.78 | 2.04 | 2.59 | 1.05 | -4.06 | -14.69
9.086 | 9086
0 | 5.21 | 2.98 | 2.59 | 1.05 | -3.41 | -15.71
9.096 | 9096
0 | 4.56 | 3.9 | 3.85 | 1.03 | -2.24 | -16.42
9.106 | 9106
0 | 3.95 | 4.77 | 3.85 | 0.98 | -1.64 | -16.78

9.116 | 9116
0 | 3.35 | 5.56 | 3.85 | 0.97 | -1.02 | -16.78
9.126 | 9126
0 | 2.71 | 6.27 | 3.85 | 0.95 | -0.07 | -16.44
9.136 | 9136
0 | 2.09 | 6.88 | 3.85 | 0.95 | 0.58 | -15.8
9.148 | 9148
0 | 1.46 | 7.47 | 3.85 | 0.92 | 0.85 | -15.6
9.158 | 9158
0 | 0.92 | 7.83 | 3.57 | 0.91 | 1.61 | -13.71
9.168 | 9168
0 | 0.4 | 8.07 | 3.57 | 0.91 | 2.12 | -12.27
9.179 | 9179
0 | -0.06 | 8.18 | 3.57 | 0.91 | 2.36 | -10.7
9.188 | 9188
0 | -0.49 | 8.18 | 3.57 | 0.91 | 2.75 | -9.07
9.198 | 9198
0 | -0.88 | 8.07 | 3.57 | 0.91 | 2.97 | -7.42
9.208 | 9208
0 | -1.18 | 7.87 | 3.57 | 0.9 | 2.94 | -5.81
9.219 | 9219
0 | -1.44 | 7.6 | 3.57 | 0.88 | 3.03 | -4.32
9.228 | 9228
0 | -1.63 | 7.28 | 3.51 | 0.87 | 2.91 | -2.95
9.238 | 9238
0 | -1.75 | 6.91 | 3.51 | 1.03 | 2.72 | -1.76
9.248 | 9248
0 | -1.75 | 6.53 | 3.51 | 0.9 | 2.08 | -0.72
9.259 | 9259
0 | -1.73 | 6.14 | 3.51 | 0.89 | 1.96 | 0.06
9.269 | 9269
0 | -1.57 | 5.76 | 3.51 | 0.91 | 1.11 | 0.69
9.324 | 9324
0 | 0.86 | 4.19 | 3.78 | 1.02 | -3.2 | 1.85
9.334 | 9334
0 | 1.45 | 3.99 | 3.78 | 1.04 | -4.68 | 1.58
9.345 | 9345
0 | 2.15 | 3.85 | 3.78 | 1.06 | -6.09 | 1.16
9.355 | 9355
0 | 2.95 | 3.76 | 3.37 | 1.07 | -7.55 | 0.84
9.364 | 9364
0 | 3.82 | 3.7 | 3.37 | 1.07 | -8.92 | 0.64
9.374 | 9374
0 | 4.67 | 3.65 | 3.37 | 1.06 | -9.86 | 0.53
9.384 | 9384
0 | 5.57 | 3.62 | 3.37 | 1.06 | -11.17 | 0.53
9.395 | 9395
0 | 6.45 | 3.58 | 3.37 | 1.02 | -12.16 | 0.55
9.405 | 9405
0 | 7.28 | 3.54 | 3.37 | 1.04 | -12.9 | 0.64
9.414 | 9414
0 | 8.08 | 3.49 | 3.37 | 1 | -13.7 | 0.77
9.424 | 9424
0 | 8.84 | 3.43 | 3.63 | 0.97 | -14.41 | 0.93
9.435 | 9435
0 | 9.52 | 3.36 | 3.63 | 0.95 | -14.79 | 1.1
9.445 | 9445
0 | 10.12 | 3.29 | 3.63 | 0.95 | -15.19 | 1.27
9.481 | 9481
0 | 12.21 | 3 | 3.63 | 0.96 | -17.54 | 1.93
9.491 | 9491
0 | 12.52 | 2.91 | 3.95 | 0.98 | -16.58 | 1.79
9.5 | 9500
0 | 12.71 | 2.83 | 3.95 | 0.97 | -16.21 | 1.84
9.51 | 9510
0 | 12.78 | 2.76 | 3.95 | 1 | -15.68 | 1.82
9.521 | 9521
0 | 12.75 | 2.7 | 3.95 | 0.98 | -15.11 | 1.74
9.531 | 9531
0 | 12.61 | 2.65 | 3.95 | 1.01 | -14.43 | 1.6
9.541 | 9541
0 | 12.37 | 2.62 | 3.95 | 1.02 | -13.68 | 1.43
9.55 | 9550
0 | 12.08 | 2.6 | 2.72 | 1.02 | -13 | 1.24
9.561 | 9561
0 | 11.7 | 2.6 | 2.72 | 1.02 | -12.18 | 1.06
9.571 | 9571
0 | 11.26 | 2.61 | 2.72 | 1 | -11.31 | 0.89
9.581 | 9581
0 | 10.76 | 2.62 | 2.72 | 0.99 | -10.39 | 0.76
9.59 | 9590
0 | 10.2 | 2.64 | 2.72 | 0.97 | -9.45 | 0.64
9.608 | 9608
0 | 9.26 | 2.67 | 2.72 | 1 | -8.28 | 0.67
9.617 | 9617
0 | 8.6 | 2.68 | 2.34 | 0.98 | -7.02 | 0.57
9.627 | 9627
0 | 7.9 | 2.68 | 2.34 | 0.99 | -5.97 | 0.62
9.637 | 9637
0 | 7.14 | 2.67 | 2.34 | 0.97 | -4.75 | 0.73
9.648 | 9648
0 | 6.33 | 2.65 | 2.34 | 1.01 | -3.55 | 0.91
9.657 | 9657
0 | 5.52 | 2.6 | 2.34 | 1.01 | -2.59 | 1.15
9.667 | 9667
0 | 4.67 | 2.53 | 2.34 | 1 | -1.35 | 1.47
9.677 | 9677
0 | 3.78 | 2.43 | 2.34 | 0.99 | -0.11 | 1.84
9.688 | 9688
0 | 2.86 | 2.3 | 1.66 | 1 | 1.16 | 2.25
9.697 | 9697
0 | 1.93 | 2.15 | 1.66 | 0.98 | 2.33 | 2.67
9.707 | 9707
0 | 1.02 | 1.97 | 1.66 | 1 | 3.33 | 3.11
9.717 | 9717
0 | 0.11 | 1.77 | 1.66 | 1.01 | 4.43 | 3.5
9.728 | 9728
0 | -0.77 | 1.56 | 1.66 | 0.98 | 5.32 | 3.87
9.74 | 9740
0 | -1.76 | 1.29 | 1.66 | 0.99 | 6.17 | 4.41
9.749 | 9749
0 | -2.5 | 1.06 | 2.48 | 0.99 | 6.68 | 4.55
9.759 | 9759
0 | -3.19 | 0.83 | 2.48 | 0.98 | 7.29 | 4.8

9.769 | 9769
0 | -3.83 | 0.6 | 2.48 | 0.99 | 7.8 | 4.96
9.78 | 9780
0 | -4.42 | 0.39 | 2.48 | 0.98 | 8.25 | 5.03
9.789 | 9789
0 | -4.9 | 0.19 | 2.48 | 1.01 | 8.31 | 4.98
9.799 | 9799
0 | -5.35 | 0.01 | 2.48 | 1 | 8.65 | 4.86
9.809 | 9809
0 | -5.61 | -0.14 | 2.48 | 0.99 | 8.04 | 4.63
9.82 | 9820
0 | -5.77 | -0.26 | 1.75 | 1.06 | 7.7 | 4.36
9.83 | 9830
0 | -5.83 | -0.35 | 1.75 | 1.03 | 7.3 | 4.03
9.839 | 9839
0 | -5.82 | -0.41 | 1.75 | 1.03 | 6.91 | 3.66
9.849 | 9849
0 | -5.68 | -0.45 | 1.75 | 1.04 | 6.12 | 3.28
9.86 | 9860
0 | -5.42 | -0.45 | 1.75 | 1.03 | 5.21 | 2.85
9.904 | 9904
0 | -4.55 | -0.34 | 2.71 | 1.08 | 4.48 | 2.97
9.913 | 9913
0 | -4.04 | -0.29 | 2.71 | 1.07 | 2.31 | 1.81
9.923 | 9923
0 | -3.46 | -0.22 | 2.71 | 1.08 | 1.21 | 1.35
9.933 | 9933
0 | -2.81 | -0.12 | 2.71 | 1.08 | 0.16 | 0.88
9.944 | 9944
0 | -2.11 | 0 | 2.18 | 1.08 | -1 | 0.41
9.953 | 9953
0 | -1.36 | 0.14 | 2.18 | 1.05 | -2.12 | -0.05
9.963 | 9963
0 | -0.55 | 0.29 | 2.18 | 1.05 | -3.38 | -0.5
9.973 | 9973
0 | 0.28 | 0.46 | 2.18 | 1.07 | -4.47 | -0.92
9.984 | 9984
0 | 1.11 | 0.63 | 2.18 | 1.01 | -5.51 | -1.31
9.993 | 9993
0 | 1.96 | 0.82 | 2.18 | 1.02 | -6.57 | -1.69
10.003 | 10003
0 | 2.8 | 1.02 | 2.18 | 1.02 | -7.6 | -2.04
10.013 | 10013
0 | 3.62 | 1.21 | 2.55 | 0.98 | -8.41 | -2.34
10.037 | 10037
0 | 5.58 | 1.68 | 2.55 | 0.98 | -10.8 | -3.14
10.054 | 10054
0 | 6.91 | 1.99 | 2.55 | 0.95 | -12.22 | -3.46
10.064 | 10064
0 | 7.65 | 2.17 | 2.55 | 0.94 | -12.83 | -3.32
10.075 | 10075
0 | 8.29 | 2.33 | 3.96 | 0.9 | -13.16 | -3.33
10.084 | 10084
0 | 8.91 | 2.48 | 3.96 | 0.9 | -13.8 | -3.32
10.094 | 10094
0 | 9.44 | 2.61 | 3.96 | 0.89 | -13.95 | -3.28
10.104 | 10104
0 | 9.88 | 2.74 | 3.96 | 0.9 | -14.11 | -3.25
10.115 | 10115
0 | 10.26 | 2.85 | 3.96 | 0.91 | -14.16 | -3.2
10.124 | 10124
0 | 10.55 | 2.96 | 3.96 | 0.93 | -14.14 | -3.17
10.134 | 10134
0 | 10.78 | 3.05 | 3.96 | 0.93 | -14.07 | -3.1
10.144 | 10144
0 | 10.98 | 3.13 | 3.4 | 0.96 | -14.17 | -2.98
10.155 | 10155
0 | 11.08 | 3.2 | 3.4 | 0.98 | -13.81 | -2.78
10.164 | 10164
0 | 11.12 | 3.24 | 3.4 | 1 | -13.55 | -2.5
10.183 | 10183
0 | 11.1 | 3.25 | 3.4 | 1.02 | -13.25 | -2.41
10.193 | 10193
0 | 10.95 | 3.23 | 3.4 | 1.02 | -12.43 | -1.6
10.204 | 10204
0 | 10.71 | 3.17 | 3.27 | 1.02 | -11.65 | -1.1
10.213 | 10213
0 | 10.39 | 3.08 | 3.64 | 1.03 | -10.88 | -0.61
10.223 | 10223
0 | 10.01 | 2.97 | 3.64 | 1.02 | -10.1 | -0.14
10.233 | 10233
0 | 9.59 | 2.84 | 3.64 | 1.01 | -9.42 | 0.3
10.244 | 10244
0 | 9.1 | 2.7 | 3.64 | 1.02 | -8.46 | 0.69
10.253 | 10253
0 | 8.58 | 2.54 | 3.64 | 1.01 | -7.69 | 1.07
10.263 | 10263
0 | 8.01 | 2.37 | 3.64 | 1.02 | -6.78 | 1.46
10.273 | 10273
0 | 7.45 | 2.18 | 3.41 | 0.98 | -6.14 | 1.89
10.284 | 10284
0 | 6.86 | 1.98 | 3.41 | 1.02 | -5.26 | 2.35
10.293 | 10293
0 | 6.24 | 1.76 | 3.41 | 1.04 | -4.38 | 2.85
10.315 | 10315
0 | 4.98 | 1.19 | 3.41 | 1.05 | -3.09 | 4.23
10.326 | 10326
0 | 4.39 | 0.89 | 3.41 | 1.07 | -2.31 | 4.71
10.335 | 10335
0 | 3.78 | 0.55 | 3.83 | 1.04 | -1.53 | 5.53
10.345 | 10345
0 | 3.15 | 0.17 | 3.83 | 1.05 | -0.64 | 6.35
10.355 | 10355
0 | 2.54 | -0.24 | 3.83 | 1.06 | 0.03 | 7.14
10.365 | 10365
0 | 1.95 | -0.68 | 3.83 | 1.05 | 0.57 | 7.84
10.375 | 10375
0 | 1.44 | -1.14 | 3.83 | 1.06 | 0.83 | 8.5
10.385 | 10385
0 | 1 | -1.61 | 3.83 | 1.05 | 1.02 | 9.14
10.395 | 10395
0 | 0.66 | -2.1 | 3.83 | 1.07 | 0.9 | 9.77
10.405 | 10405
0 | 0.39 | -2.61 | 3.7 | 1.06 | 0.89 | 10.4
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

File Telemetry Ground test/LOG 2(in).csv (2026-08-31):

Time_s | Time_ms | State | Pitch | Yaw | Altitude | GForce | OutputPitch | OutputYaw
5.978 | 5978 | 0 | 0.02 | 0.08 | 2.93 | 0.98 | -0.12 | -0.91
6.001 | 6001 | 0 | -0.07 | 0.08 | 2.93 | 0.99 | 0.28 | -0.1
6.012 | 6012 | 0 | -0.1 | 0 | 2.93 | 0.99 | 0.26 | 0.71
6.023 | 6023 | 0 | -0.13 | -0.13 | 2.81 | 1 | 0.29 | 1.44
6.033 | 6033 | 0 | -0.15 | -0.3 | 2.81 | 1 | 0.26 | 2.13
6.042 | 6042 | 0 | -0.19 | -0.51 | 2.81 | 1.01 | 0.46 | 2.76
6.052 | 6052 | 0 | -0.27 | -0.74 | 2.81 | 1.01 | 0.72 | 3.36
6.063 | 6063 | 0 | -0.44 | -1 | 2.81 | 1.01 | 1.35 | 3.88
6.073 | 6073 | 0 | -0.61 | -1.27 | 2.81 | 1.02 | 1.6 | 4.33
6.082 | 6082 | 0 | -0.82 | -1.55 | 2.81 | 1 | 2.05 | 4.73
6.092 | 6092 | 0 | -1.01 | -1.84 | 3.15 | 1.01 | 2.17 | 5.11
6.103 | 6103 | 0 | -1.22 | -2.13 | 3.15 | 1 | 2.49 | 5.46
6.117 | 6117 | 0 | -1.54 | -2.56 | 3.15 | 1.01 | 2.97 | 6.31
6.126 | 6126 | 0 | -1.7 | -2.86 | 3.15 | 1.01 | 2.83 | 6.35
6.136 | 6136 | 0 | -1.8 | -3.18 | 3.15 | 1 | 2.67 | 6.72
6.147 | 6147 | 0 | -1.89 | -3.5 | 3.15 | 0.99 | 2.7 | 7.08
6.157 | 6157 | 0 | -1.95 | -3.84 | 3.64 | 0.97 | 2.66 | 7.41
6.167 | 6167 | 0 | -2.01 | -4.17 | 3.64 | 0.96 | 2.71 | 7.67
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

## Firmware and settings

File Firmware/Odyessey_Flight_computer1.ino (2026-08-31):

#include <Wire.h>
#include <SPI.h>
#include <SD.h>
#include <Servo.h>
#include <math.h>
#include <Adafruit_BMP280.h>

const int SD_CS       = 10;
const int Servo_X     = 5;
const int Servo_Y     = 6;
const int Servo_CHUTE = 9;

const int BUZZER_PIN  = 3;
const int LED_PIN     = 2;

const int PARACHUTE_LOCKED   = 0;    
const int PARACHUTE_UNLOCKED = 180;  

Servo servoX;
Servo servoY;
Servo servochute;

const float SERVO_X_CENTER   = 90.0f;
const float SERVO_Y_CENTER   = 90.0f;
const float MAX_GIMBAL_ANGLE = 15.0f;

const float SERVO_X_DIRECTION_SIGN = -1.0f; 

Adafruit_BMP280 bmp;

float currentAltitude = 0.0f;
float maxAltitude     = 0.0f;
float groundAltitude  = 0.0f;

const uint8_t MPU_ADDR = 0x68;

float accX = 0.0f, accY = 0.0f, accZ = 0.0f;
float totalGForce = 1.0f;
float gyroX = 0.0f, gyroY = 0.0f, gyroZ = 0.0f;
float gyroX_offset = 0.0f, gyroY_offset = 0.0f, gyroZ_offset = 0.0f;

const float GYRO_FILTER_ALPHA = 0.20f;
float filteredGyroX = 0.0f, filteredGyroY = 0.0f, filteredGyroZ = 0.0f;

float pitch = 0.0f;
float yaw   = 0.0f;
const float YAW_DIRECTION_SIGN = 1.0f;

float targetPitch = 0.0f;
float targetYaw   = 0.0f;
const float YAW_FOLLOW_ALPHA = 0.05f; 

float Kp_pitch = 1.2f, Ki_pitch = 0.0f, Kd_pitch = 0.05f;
float Kp_yaw   = 2.0f, Ki_yaw   = 0.0f, Kd_yaw   = 0.10f;

float pitchIntegral = 0.0f, yawIntegral = 0.0f;
float previousPitchError = 0.0f, previousYawError = 0.0f;

float pitchOutput = 0.0f;
float yawOutput   = 0.0f;

enum Flightstate {
  PAD,
  IGNITION,
  COAST,
  APOGEE,
  LANDED
};

Flightstate currentstate = PAD;

uint32_t launchTime      = 0;
uint32_t burnoutTime     = 0;
uint32_t lastLoopTime    = 0;
const uint32_t LOOP_INTERVAL_US = 10000;

const uint32_t MIN_IGNITION_TIME_MS = 1500; 

File logFile;
bool sdInitialized = false;

void initMPU6050() {
  Wire.beginTransmission(MPU_ADDR);
  Wire.write(0x6B); Wire.write(0x00);
  Wire.endTransmission();

  Wire.beginTransmission(MPU_ADDR);
  Wire.write(0x1C); Wire.write(0x00); 
  Wire.endTransmission();

  Wire.beginTransmission(MPU_ADDR);
  Wire.write(0x1B); Wire.write(0x00); 
  Wire.endTransmission();
}

bool readMPU6050() {
  Wire.beginTransmission(MPU_ADDR);
  Wire.write(0x3B);
  if (Wire.endTransmission(false) != 0) return false;

  if (Wire.requestFrom(MPU_ADDR, (uint8_t)14) != 14) return false;

  int16_t rawAccX  = (Wire.read() << 8) | Wire.read();
  int16_t rawAccY  = (Wire.read() << 8) | Wire.read();
  int16_t rawAccZ  = (Wire.read() << 8) | Wire.read();
  Wire.read(); Wire.read();
  int16_t rawGyroX = (Wire.read() << 8) | Wire.read();
  int16_t rawGyroY = (Wire.read() << 8) | Wire.read();
  int16_t rawGyroZ = (Wire.read() << 8) | Wire.read();

  accX = rawAccX / 16384.0f;
  accY = rawAccY / 16384.0f;
  accZ = rawAccZ / 16384.0f;

  totalGForce = sqrt(accX * accX + accY * accY + accZ * accZ);

  gyroX = (rawGyroX / 131.0f) - gyroX_offset;
  gyroY = (rawGyroY / 131.0f) - gyroY_offset;
  gyroZ = (rawGyroZ / 131.0f) - gyroZ_offset;

  filteredGyroX += GYRO_FILTER_ALPHA * (gyroX - filteredGyroX);
  filteredGyroY += GYRO_FILTER_ALPHA * (gyroY - filteredGyroY);
  filteredGyroZ += GYRO_FILTER_ALPHA * (gyroZ - filteredGyroZ);

  gyroX = filteredGyroX;
  gyroY = filteredGyroY;
  gyroZ = filteredGyroZ;

  return true;
}

void calibrateGyro() {
  Serial.println(F("CALIBRATING GYRO... KEEP STILL"));
  delay(1000);
  float sumX = 0, sumY = 0, sumZ = 0;
  int valid = 0;

  for (int i = 0; i < 500; i++) {
    if (readMPU6050()) {
      sumX += gyroX; sumY += gyroY; sumZ += gyroZ;
      valid++;
    }
    delay(3);
  }

  if (valid > 0) {
    gyroX_offset = sumX / valid;
    gyroY_offset = sumY / valid;
    gyroZ_offset = sumZ / valid;
  }
}

void updateAttitude(float dt) {
  float accelPitch = atan2(-accX, sqrt(accY * accY + accZ * accZ)) * 180.0f / M_PI;
  pitch = 0.98f * (pitch + gyroX * dt) + 0.02f * accelPitch;

  yaw += (gyroZ * YAW_DIRECTION_SIGN) * dt;

  targetYaw += YAW_FOLLOW_ALPHA * (yaw - targetYaw);

  if (yaw > 180.0f)  yaw -= 360.0f;
  if (yaw < -180.0f) yaw += 360.0f;
}

void updateGimbal(float dt) {
  float pitchError = targetPitch - pitch;
  pitchOutput = (Kp_pitch * pitchError) + (Kd_pitch * (pitchError - previousPitchError) / dt);
  previousPitchError = pitchError;

  float yawError = targetYaw - yaw;
  if (yawError > 180.0f)  yawError -= 360.0f;
  if (yawError < -180.0f) yawError += 360.0f;

  yawOutput = (Kp_yaw * yawError) + (Kd_yaw * (yawError - previousYawError) / dt);
  previousYawError = yawError;

  float rawServoX = SERVO_X_CENTER + (SERVO_X_DIRECTION_SIGN * pitchOutput);
  float servoXAngle = constrain(rawServoX, SERVO_X_CENTER - MAX_GIMBAL_ANGLE, SERVO_X_CENTER + MAX_GIMBAL_ANGLE);

  float rawServoY = SERVO_Y_CENTER + yawOutput;
  float servoYAngle = constrain(rawServoY, SERVO_Y_CENTER - MAX_GIMBAL_ANGLE, SERVO_Y_CENTER + MAX_GIMBAL_ANGLE);

  servoX.write((int)servoXAngle);
  servoY.write((int)servoYAngle);
}

void initSDCard() {
  Serial.print(F("Initializing SD card..."));
  
  if (!SD.begin(SD_CS)) {
    Serial.println(F("SD Initialization Failed!"));
    sdInitialized = false;
    return;
  }

  sdInitialized = true;
  Serial.println(F("SD Card Ready."));

  logFile = SD.open("log.csv", FILE_WRITE);
  if (logFile) {
    logFile.println(F("Time_ms,State,Pitch,Yaw,Altitude,GForce,OutputPitch,OutputYaw"));
    logFile.flush();
  }
}

void logTelemetry() {
  if (!sdInitialized || !logFile) return;

  logFile.print(millis());
  logFile.print(F(","));
  logFile.print(currentstate);
  logFile.print(F(","));
  logFile.print(pitch);
  logFile.print(F(","));
  logFile.print(yaw);
  logFile.print(F(","));
  logFile.print(currentAltitude);
  logFile.print(F(","));
  logFile.print(totalGForce);
  logFile.print(F(","));
  logFile.print(pitchOutput);
  logFile.print(F(","));
  logFile.println(yawOutput);

  static uint32_t lastFlush = 0;
  if (millis() - lastFlush > 1000) {
    lastFlush = millis();
    logFile.flush();
  }
}

void updateIndicators() {
  switch (currentstate) {
    case PAD:
      digitalWrite(LED_PIN, (millis() / 500) % 2);
      noTone(BUZZER_PIN);
      break;

    case IGNITION:
      digitalWrite(LED_PIN, (millis() / 100) % 2);
      tone(BUZZER_PIN, 2400); 
      break;

    case COAST:
      digitalWrite(LED_PIN, (millis() / 100) % 2);
      if ((millis() / 150) % 2) {
        tone(BUZZER_PIN, 1500);
      } else {
        noTone(BUZZER_PIN);
      }
      break;

    case APOGEE:
      digitalWrite(LED_PIN, HIGH);
      tone(BUZZER_PIN, 2200); 
      break;

    case LANDED:
      digitalWrite(LED_PIN, HIGH);
      if ((millis() / 1000) % 2) {
        tone(BUZZER_PIN, 1000);
      } else {
        noTone(BUZZER_PIN);
      }
      break;
  }
}

void updateStateMachine() {
  float rawAlt = bmp.readAltitude(1013.25) - groundAltitude;
  
  if (currentstate == PAD && rawAlt < 0.10f) {
    currentAltitude = 0.0f;
  } else {
    currentAltitude = rawAlt;
  }

  if (currentAltitude > maxAltitude) {
    maxAltitude = currentAltitude;
  }

  switch (currentstate) {
    case PAD:
      servochute.write(PARACHUTE_LOCKED);
      if (totalGForce > 2.0f) {
        currentstate = IGNITION;
        launchTime = millis();
        Serial.println(F("IGNITION DETECTED, LIFTOFF!"));
      }
      break;

    case IGNITION:
      servochute.write(PARACHUTE_LOCKED);
      if (totalGForce < 0.8f && (millis() - launchTime > MIN_IGNITION_TIME_MS)) {
        currentstate = COAST;
        burnoutTime = millis();
        Serial.println(F("BURNOUT DETECTED, COASTING..."));
      }
      break;

    case COAST:
      servochute.write(PARACHUTE_LOCKED);
      {
        bool altitudeApogee = (maxAltitude > 0.5f) && (currentAltitude <= (maxAltitude - 0.3f));
        bool timerApogee    = (millis() - burnoutTime > 2500);

        if (altitudeApogee || timerApogee) {
          currentstate = APOGEE;
          Serial.println(F("SINGLE APOGEE DETECTED -> DEPLOYING PARACHUTE IMMEDIATELY!"));
          Serial.print(F("MAX ALTITUDE: "));
          Serial.println(maxAltitude);
        }
      }
      break;

    case APOGEE:
      servochute.write(PARACHUTE_UNLOCKED);

      static uint32_t chuteDeployTime = 0;
      if (chuteDeployTime == 0) chuteDeployTime = millis();

      if (millis() - chuteDeployTime > 2000) {
        currentstate = LANDED;
        Serial.println(F("ROCKET LANDED"));
      }
      break;

    case LANDED:
      servochute.write(PARACHUTE_UNLOCKED);
      break;
  }
}

void processParachuteOutput() {
  if (currentstate == APOGEE || currentstate == LANDED) {
    servochute.write(PARACHUTE_UNLOCKED);
  } else {
    servochute.write(PARACHUTE_LOCKED);
  }
}

void setup() {
  Serial.begin(115200);

  Wire.begin();

  pinMode(LED_PIN, OUTPUT);
  pinMode(BUZZER_PIN, OUTPUT);
  digitalWrite(LED_PIN, LOW);

  if (bmp.begin(0x76) || bmp.begin(0x77)) {
    Serial.println(F("BMP280 Initialized."));
  } else {
    Serial.println(F("BMP280 Init Failed!"));
  }

  delay(200);
  float altSum = 0;
  for (int i = 0; i < 50; i++) {
    altSum += bmp.readAltitude(1013.25);
    delay(20);
  }
  groundAltitude = altSum / 50.0f;
  currentAltitude = 0.0f;
  maxAltitude = 0.0f;

  initMPU6050();
  calibrateGyro();
  initSDCard();

  servoX.attach(Servo_X);
  servoY.attach(Servo_Y);
  servochute.attach(Servo_CHUTE);

  servoX.write((int)SERVO_X_CENTER);
  servoY.write((int)SERVO_Y_CENTER);
  servochute.write(PARACHUTE_LOCKED);

  for (int i = 0; i < 3; i++) {
    tone(BUZZER_PIN, 2000);
    digitalWrite(LED_PIN, HIGH);
    delay(80);
    noTone(BUZZER_PIN);
    digitalWrite(LED_PIN, LOW);
    delay(80);
  }

  lastLoopTime = micros();
}

void loop() {
  uint32_t now = micros();
  uint32_t elapsed = now - lastLoopTime;

  if (elapsed >= LOOP_INTERVAL_US) {
    lastLoopTime = now;
    float dt = elapsed / 1000000.0f;

    if (dt > 0.0f && dt < 0.1f && readMPU6050()) {
      updateAttitude(dt);
      updateGimbal(dt);
      updateStateMachine();
      processParachuteOutput();
      updateIndicators();
      logTelemetry();
    }

    static uint32_t lastPrint = 0;
    if (millis() - lastPrint > 1000) {
      lastPrint = millis();
      Serial.print(F("State: ")); Serial.print(currentstate);
      Serial.print(F(" | Pitch: ")); Serial.print(pitch);
      Serial.print(F(" | Yaw: ")); Serial.print(yaw);
      Serial.print(F(" | G-Force: ")); Serial.print(totalGForce);
      Serial.print(F(" | Alt: ")); Serial.println(currentAltitude);
    }
  }
}

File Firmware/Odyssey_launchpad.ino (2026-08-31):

const int CH_1 = 3;     
const int CH_2 = 4;     
const int CH_3 = 5;     

const int RELAY_PIN = 6; 
const int LED_PIN   = 7; 
const int BUZZER    = 1; 

int step = 0; 

void setup() {
  pinMode(BTN_1, INPUT_PULLUP);
  pinMode(BTN_2, INPUT_PULLUP);
  pinMode(BTN_3, INPUT_PULLUP);

  pinMode(RELAY_PIN, OUTPUT);
  pinMode(LED_PIN, OUTPUT);
  pinMode(BUZZER, OUTPUT);

  digitalWrite(RELAY_PIN, LOW);
  digitalWrite(LED_PIN, LOW);
  digitalWrite(BUZZER, LOW);
}

void loop() {
  int b1 = digitalRead(BTN_1);
  int b2 = digitalRead(BTN_2);
  int b3 = digitalRead(BTN_3);

  if (step == 0) {
    if (b1 == LOW) {
      digitalWrite(BUZZER, HIGH);
      delay(100);
      digitalWrite(BUZZER, LOW);

      digitalWrite(LED_PIN, HIGH); 
      step = 1;

      delay(300); 
    } 
    else if (b2 == LOW || b3 == LOW) {
      digitalWrite(BUZZER, HIGH);
      delay(400);
      digitalWrite(BUZZER, LOW);
      digitalWrite(LED_PIN, LOW);
      step = 0;
      delay(300);
    }
  }

  if (step == 1) {
    if (b2 == LOW) {
      digitalWrite(BUZZER, HIGH);
      delay(100);
      digitalWrite(BUZZER, LOW);

      step = 2;

      delay(300); 
    } 
    else if (b1 == LOW || b3 == LOW) {
      digitalWrite(BUZZER, HIGH);
      delay(400);
      digitalWrite(BUZZER, LOW);
      digitalWrite(LED_PIN, LOW);
      step = 0;
      delay(300);
    }
  }

  if (step == 2) {
    if (b3 == LOW) {
      digitalWrite(RELAY_PIN, HIGH); 

      digitalWrite(BUZZER, HIGH);
      delay(150);
      digitalWrite(BUZZER, LOW);
      delay(100);
      digitalWrite(BUZZER, HIGH);
      delay(300);
      digitalWrite(BUZZER, LOW);

      step = 3; 
    } 
    else if (b1 == LOW || b2 == LOW) {
      digitalWrite(BUZZER, HIGH);
      delay(400);
      digitalWrite(BUZZER, LOW);
      digitalWrite(LED_PIN, LOW);
      step = 0;
      delay(300);
    }
  }
}

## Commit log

2026-08-31 Create Telemetry Ground test
2026-08-31 Update README.md for formatting and clarity
    Corrected casing of 'microsd' to 'microSD' and fixed formatting in the Wireless Launch System section. Removed the PID Closed-Loop TVC Control System diagram and updated the Flight State Machine section for clarity.
2026-08-31 Clarify motor restrictions and fix typos in README
    Updated the README to clarify the restrictions on G-class motors and correct spelling errors.
2026-08-31 Rename button constants to channel constants
2026-08-31 Corrected PID to PD controller in README
2026-08-31 Add printer settings for 3D printing models
2026-08-31 Update Printer settings.md
2026-08-31 Include PETG filament in printer settings
    Added filament type information for 3D printing.
2026-08-31 Create Printing settings.md
2026-09-01 Add code upload instructions to README
    Added instructions for uploading code to Arduino.
2026-09-01 Fix formatting and add screws to components list
